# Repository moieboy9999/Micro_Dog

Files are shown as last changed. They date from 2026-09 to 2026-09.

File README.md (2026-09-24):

# Micro Dog

-Since the creator is Korean, the filename contains Korean.-

A 0.96 kg, 12-DOF quadruped driven by 12 × Dynamixel XL330-M288-T servos. It is built around a
Raspberry Pi Zero 2 W and uses a parallelogram four-bar knee.

This repository contains the complete mechanical design and the simulation description:
- the Autodesk Inventor source;
- a neutral STEP export;
- per-link visual meshes;
- a URDF with measured masses and joint limits;
- a flattened USD for Isaac Sim / Isaac Lab;
- the scripts that regenerate the URDF from the CAD data;
- the trained walking policy that runs on the robot (`policy/`).

[한국어 요약](README.ko.md) · [Notes from the creator](A%20small%20note%20from%20the%20creator.md)

> **Bill of materials: coming soon.** A full BOM (electronics, bearings, fasteners, printed parts
> with quantities and filament estimate) will be added in a later update.

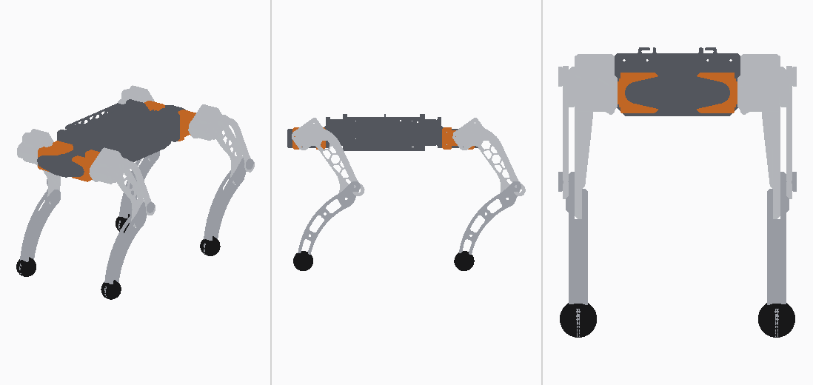
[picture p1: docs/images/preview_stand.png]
Micro Dog in its standing pose


| | |
|---|---|
| Mass | **0.960 kg** (weighed) |
| Size | 334.5 × 165.5 × 145.2 mm (assembly pose) |
| Degrees of freedom | 12: hip roll, thigh pitch, knee pitch per leg |
| Actuators | 12 × Dynamixel XL330-M288-T (Protocol 2.0) |
| Legs | thigh 95.0 mm, shank 97.0 mm, foot radius 13.0 mm |
| Hip spacing | 206.0 mm fore-aft, 58.0 mm across |
| Standing height | 0.170 m nominal |
| Compute | Raspberry Pi Zero 2 W with a Pollen Robotics RPI Robot HAT |
| Power | 2-cell lithium pack, BMS and charging module |
| Material | PLA (3D printed) for all printed parts: frame, legs, body cover; TPU-95A feet; knee pushrod links machined from 6061 aluminium in the author's build (PLA links are strong enough) |

---

## Contents

```
urdf/micro_dog.urdf        the model: 17 links, 16 joints (12 revolute + 4 fixed feet)
meshes/visual/*.stl        9 binary STLs (~19 MB), visual only; paths are relative to the URDF
step/micro_dog.step        full assembly, neutral CAD exchange (Inventor export)
usd/micro_dog.usda         pre-converted and flattened asset for Isaac Sim / Isaac Lab
params/robot_params.yaml   masses, inertias, joint origins, measured limits, actuator constants
params/*.json              raw Inventor dumps (assembly tree, mass properties) the params derive from
cad/inventor/              Autodesk Inventor 2027 source (assembly + parts)
tools/                     generate_urdf.py, derive_params.py, bake_meshes.py, stl_io.py
docs/specs.md              coordinate frames, dimensions, mass budget, knee linkage, servo zero/sign
docs/body_cover.md         the body cover, which is in the Inventor source but not in the URDF
policy/                    trained walking policy (RSL-RL checkpoint) and its deployment contract
```

**Which version is which.**
- `urdf/`, `meshes/`, `step/`, `usd/` and `params/` are the **2026-08-23 CAD export**. That is the
  version used for all simulation and training.
- `cad/inventor/` is the **current design (2026-09-21)**. It adds the body cover and small revisions
  to the foot and the Pi mount.
- The body cover is not in the simulation model. It is printed in PLA: about 50.8 g if
  solid, less with infill (see `docs/body_cover.md`).

---

## Loading the model

**Isaac Sim / Isaac Lab.** Start with `usd/micro_dog.usda`. It is already converted and flattened,
with no external references and no absolute paths.

If you convert the URDF yourself, **flatten the result**. The Isaac Sim URDF importer nests links
as a kinematic tree (`base/FL_hip/FL_thigh/...`). Isaac Lab's contact sensing assumes the flat
layout of its stock assets. In the nested layout only `base` gets `PhysxContactReportAPI`, and the
feet silently report no contacts.

**Other simulators (ROS, PyBullet, MuJoCo import, …).** Load `urdf/micro_dog.urdf`. Keep `urdf/` and
`meshes/` side by side, because meshes are referenced as `../meshes/visual/*.stl`.

Link and joint names follow the Unitree Go2 convention, so Go2 configurations need few edits:

```
base
 └ {FL,FR,RL,RR}_hip    ← *_hip_joint    revolute, axis (1,0,0)  roll
    └ *_thigh           ← *_thigh_joint  revolute, axis (0,1,0)  pitch
       └ *_calf         ← *_calf_joint   revolute, axis (0,1,0)  knee
          └ *_foot      ← *_foot_joint   fixed
```

Frame: ROS convention (+X forward, +Y left, +Z up); SI units.

## Joints

**Zero pose** is the CAD assembly pose, with every servo centred at 2048 ticks. At zero the thighs
point straight back and the shanks straight down.

| Joint | Axis | Lower (rad) | Upper (rad) |
|---|---|---:|---:|
| `*_hip_joint`, left (FL, RL) | `1 0 0` | −1.5555 | +0.8606 |
| `*_hip_joint`, right (FR, RR) | `1 0 0` | −0.8606 | +1.5555 |
| `*_thigh_joint` | `0 1 0` | −1.5278 | +0.8590 |
| `*_calf_joint` | `0 1 0` | −1.1014 | +1.2072 |

- **Limits** were measured on the assembled robot. The hip limits are mirrored between left and
  right.
- **Every revolute joint** has effort 0.6405 N·m and velocity 20.22 rad/s. These are the XL330
  values at this robot's supply voltage.
- **Joint dynamics** are damping 0.00536 and friction 0.00477.

**The knee is exact, not approximated.** The knee servo sits in the thigh and drives the shank
through a parallelogram four-bar (crank 19 mm, pushrod 95 mm). The shank angle relative to the
thigh therefore equals the servo angle 1:1. See `docs/specs.md` §3.

## Masses

| Link | Mass (kg) | ×4 |
|---|---:|---:|
| `base` | 0.45564 | — |
| `*_hip` | 0.03357 | 0.13428 |
| `*_thigh` | 0.06676 | 0.26704 |
| `*_calf` | 0.02376 | 0.09504 |
| `*_foot` | 0.00200 | 0.00800 |
| **Total** | | **0.96000** |

- The CAD sums to 912.6 g and the weighed robot is 960 g.
- The 47.4 g difference (wiring, screws, glue) is spread evenly over the four thighs and four
  calves.
- Their inertia tensors are scaled by the same ratio.

## Collision model: read this before you trust contacts

Collision uses **primitives only**: 13 boxes and 4 foot spheres of radius 0.013 m. There are no
collision meshes.

The foot sphere's lowest point matches the real foot tip (within 0.1 mm), so contact **height** is
right. The real foot is a thin blade, though, so contact **width** is about 2× too generous
laterally. For slip or contact-patch studies, model the real geometry. For gait and balance work
the sphere is fine.

## Regenerating the URDF

```
python tools/derive_params.py     # params/*.json (Inventor dumps) -> params/robot_params.yaml
python tools/generate_urdf.py     # params/robot_params.yaml       -> urdf/micro_dog.urdf
python tools/bake_meshes.py --raw <dir with raw Inventor STL exports>   # -> meshes/visual/
```

- `generate_urdf.py` reproduces `urdf/micro_dog.urdf` exactly from the shipped params (line endings follow your OS).
- The raw per-document STL exports (~240 MB) are not shipped. Export them from `cad/inventor/`.
- Requires Python 3 with `numpy` and `pyyaml`.

## Inventor source

- Open `cad/inventor/micro_dog.ipj` as the Inventor project, then `cad/inventor/전체.iam`
  ("full assembly"). The project workspace is the folder itself, so the set works from any
  location.
- The files were made with **Autodesk Inventor 2027 Education**. Inventor marks them as
  educational, and that mark stays with them if they are opened in a commercial seat.
- File names are Korean. Key terms: 다리 = leg, 몸 = body, 부품 = purchased parts, 허벅지 = thigh,
  종아리 = shank, 발 = foot, 프레임 = frame, 커버 = cover.
- **One model is not included:** `몸/시스템/Raspberry Pi Zero 2 W.ipt`. It is a third-party model.
  Download a Raspberry Pi Zero 2 W STEP model (for example from the official Raspberry Pi
  product page), import it into Inventor and save it under that name and path to restore the
  assembly. Everything else resolves inside this folder.

## Not included

- The actuator model: friction, torque–speed curve, transport delay.
- The training environment code. The walking policy and its observation/action contract are in
  `policy/`.
- IMU placement and calibration. Servo signs and IDs are in `docs/specs.md` §4. The homing offsets
  in `params/robot_params.yaml → hardware` belong to the author's unit; yours will differ.
- Bill of materials (coming soon), printing and assembly instructions.

## License

- **Hardware, documentation and the policy weights** (CAD, STEP, STL, URDF, USD, params, docs,
  policy) are licensed under
  **CC BY-NC-SA 4.0** — see [LICENSE](LICENSE).
- **Scripts in `tools/`** are licensed under **GPL-3.0-or-later** — see
  [LICENSE-SOFTWARE](LICENSE-SOFTWARE).
- Third-party components and credits: [ATTRIBUTION.md](ATTRIBUTION.md).

© 2026 moieboy9999

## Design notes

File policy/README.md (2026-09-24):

# Walking policy (`micro_dog_walk.pt`)

This is the velocity-tracking walking policy that runs on the author's Micro Dog, on gamepad button A
(deployed 2026-09-20). It was trained in Isaac Lab with RSL-RL (PPO) and walked on the real robot.

| File | Contents |
|---|---|
| `micro_dog_walk.pt` | RSL-RL checkpoint, update 30000: actor, critic, optimizer state, curriculum state |
| `micro_dog_walk.json` | Deployment contract: observation layout, action formula, joint order, limits, hardware settings |

## Network

- **Actor:** MLP 45 → 512 → 256 → 128 → 12, ELU activations, in `actor_state_dict` (`mlp.0/2/4/6`).
  It has no observation normalisation and no history.
- **Output:** the deterministic action is the MLP output. `distribution.log_std_param` is the training
  exploration noise; ignore it at deployment.
- **Timing:** it runs at 50 Hz (`step_dt` 0.02 s).

## Observation (45 values, raw SI units, no scaling)

| Index | Term | Meaning |
|---|---|---|
| 0–2 | `base_ang_vel` | IMU gyro, body frame, rad/s |
| 3–5 | `projected_gravity` | gravity unit vector in the body frame (complementary filter, α = 0.01) |
| 6–8 | `velocity_commands` | [vx m/s, vy m/s, yaw rate rad/s] |
| 9–20 | `joint_pos` | joint angle **minus** `default_joint_pos`, rad |
| 21–32 | `joint_vel` | joint velocity, rad/s |
| 33–44 | `actions` | previous raw policy output |

**Joint order is grouped by joint type, not by leg.** It is the `joint_names` list in the JSON:

```
FL_hip  FR_hip  RL_hip  RR_hip  FL_thigh  FR_thigh  RL_thigh  RR_thigh  FL_calf  FR_calf  RL_calf  RR_calf
```

This differs from the per-leg order of the URDF, so map by name.

## Action

```
target = clip(raw_action * 0.25 + default_joint_pos, clip_low, clip_high)     # rad, joint_names order
```

`default_joint_pos`, `clip_low` and `clip_high` are in the JSON. Send `target` to the servos as
position setpoints.

## Hardware assumptions

- **Servos:** XL330-M288-T in position mode, firmware P gain 200. Profile velocity is 843 and
  profile acceleration 0, so the servo's own velocity profile shapes the step. The host sends raw
  targets.
- **Angle mapping:** servo tick ↔ joint angle uses `docs/specs.md` §4.
- **Training commands:** the curriculum's final stage covered |vx| ≤ 0.70 m/s, |vy| ≤ 0.50 m/s and
  |yaw rate| ≤ 1.8 rad/s. Speeds validated on hardware are lower. Start slow.
- **Physics:** the simulated actuator, IMU and friction models it was trained against are described in
  the JSON (`physics_contract`, `imu_contract`). The training environment code is not included.
- **Torque limit:** training used a PWM/voltage torque model with an effort limit of 0.549 N·m
  (`physics_contract.effort_limit_nm`). That is stricter than the 0.6405 N·m on the URDF joints, which
  is the plain rigid-body description.

## Safety

- This is a learned controller for a small robot.
- Test with the robot lifted, then at low commanded speed.
- Keep a torque-off button within reach.
- The servos' current-limit register is not enforced in position mode (see `physics_contract`).

License: CC BY-NC-SA 4.0, like the rest of the design files.

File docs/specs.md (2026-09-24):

# Micro Dog — design specifications

This document derives the URDF from the Inventor CAD. All dimensions come from the assembly. Total
mass, servo gain and supply voltage were measured on the robot.

## 1. Frames

The CAD assembly frame is +X forward, +Y up, +Z right. The URDF uses the ROS convention: +X
forward, +Y left, +Z up. One fixed rotation maps between them:

```
p_urdf = M · p_cad        M = [[1, 0, 0],
                               [0, 0,-1],
                               [0, 1, 0]]
```

The `base` origin is the centre of the four hip-roll axes, the same convention as Go2.

## 2. Dimensions (from CAD)

| Item | Value |
|---|---|
| Hip-roll axis spacing, fore-aft | 206.0 mm |
| Hip-roll axis spacing, across | 58.0 mm |
| Roll axis → leg plane (lateral offset) | 39.8 mm |
| Thigh (pitch axis → knee axis) | 95.0 mm |
| Shank (knee axis → foot pad centre) | 97.0 mm |
| Foot radius (TPU-95A foot) | 13.0 mm |
| Knee axis → ground contact | 110.0 mm |
| Track width (left–right foot spacing) | 137.6 mm |
| Maximum leg extension | 205.0 mm |

The roll, pitch and knee axes all lie in one horizontal plane, and the roll and pitch axes
intersect. The only `hip_joint → thigh_joint` offset is therefore the 39.8 mm lateral one.

### Mass budget

| Link | Mass | Contents |
|---|---|---|
| `base` | 455.6 g | frame 220.6 g; system 235.0 g (2 batteries, Pi + HAT, BMS, charger, fan, switch); 4 roll servos |
| `*_hip` ×4 | 33.6 g | roll horn frame, pitch servo, bearing |
| `*_thigh` ×4 | 66.8 g | thigh shell 22.0, XL330 22.0, large bearing 2.0, crank 2.6, pushrod 12.2 (6061 aluminium; the CAD models it at about 3.0 g/cm³, i.e. metal), **measured makeup 5.9** |
| `*_calf` ×4 | 23.8 g | shank + foot assembly minus the foot tip, **measured makeup 5.9** |
| `*_foot` ×4 | 2.0 g | TPU-95A foot tip |
| **Total** | **960.0 g** | CAD 912.6 g + makeup 47.4 g |

**Measured makeup.** The assembled robot weighs 960 g against a CAD total of 912.6 g.
- The 47.4 g the CAD does not carry is wiring, screws and glue.
- The servo cables run down the legs, so it is split evenly over the four thighs and four calves:
  +5.925 g per link.
- Each link's inertia tensor is scaled by the same ratio.
- A point mass at the COM would leave the inertia unchanged and under-state leg swing inertia.

**Material density.** CAD part masses use Inventor's ABS density (1.06 g/cm³), except where a
mass is overridden (the thigh shell is fixed at 22.0 g). All printed parts are PLA
(about 1.24 g/cm³). The weighed total of 960 g is exact. The split between links still assumes ABS
density for the printed parts.

Inertia tensors come from Inventor `MassProperties`: about the COM, in assembly axes, converted
from kg·cm² to kg·m². The sign and order convention was checked against the principal moments.

## 3. Knee: four-bar → one revolute joint

The knee servo sits in the thigh. It drives crank → pushrod → shank crank arm → shank.

| Link | Length |
|---|---|
| Thigh (ground link) | 95.0 mm |
| Crank | 19.0 mm |
| Pushrod | 95.0 mm |
| Shank crank arm | 19.0 mm |

This is an exact parallelogram, so the crank and the shank arm stay parallel. The shank angle
relative to the thigh equals the knee servo angle 1:1, with no coupling term. A single revolute
knee is therefore an exact equivalent model, not an approximation.

The pushrod (12.2 g) and crank (2.6 g) are merged into the thigh link. In a parallelogram the
pushrod always moves parallel to the thigh, so this is physically sound.

## 4. Joint zero and servo mapping

`q = 0` is the CAD assembly pose. All 12 servos are at 2048 ticks (180°). The thigh points
straight back and the shank straight down.

```
tick = 2048 + sign · q · 4096/(2π) + offset_tick
q    = sign · (tick − 2048 − offset_tick) · 2π/4096
```

| Joint | FL | FR | RL | RR |
|---|---|---|---|---|
| hip | +1 | +1 | −1 | −1 |
| thigh | +1 | −1 | +1 | −1 |
| calf | +1 | −1 | +1 | −1 |

Servo IDs are leg-major:

| | FL | FR | RL | RR |
|---|---|---|---|---|
| hip roll | 11 | 21 | 31 | 41 |
| thigh pitch | 12 | 22 | 32 | 42 |
| knee pitch | 13 | 23 | 33 | 43 |

### Poses

| Pose | hip | thigh | calf | base height |
|---|---|---|---|---|
| `zero` (assembly) | 0 | 0 | 0 | 0.110 m |
| `stand` (kinematic target) | 0 | −0.9500 | +0.3440 | 0.170 m |
| `stand_balanced` (COM over support centre) | 0 | −0.8380 | +0.3658 | 0.170 m |
| `stand_compensated` (commanded, under gravity) | +0.0084 | −0.8149 | +0.5002 | 0.168 m (target 0.170) |

`stand_compensated` is the command whose steady state under gravity approximates `stand_balanced`.
The XL330 position loop has finite stiffness, so the commanded angles have to lead the target. All
poses, including 0.155 m variants, are in `params/robot_params.yaml → poses`, which is the source
of truth for these values.

## 5. Actuator constants

`params/robot_params.yaml → actuator` holds these constants for the XL330-M288-T:
- effort limit and velocity limit;
- torque constant, winding resistance and armature;
- friction.

The friction and motor constants come from Rhoban BAM (`xl330/m6.json`; see ATTRIBUTION.md). The
effort and velocity limits are evaluated at this robot's supply voltage.

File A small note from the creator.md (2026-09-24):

1. I made the leg links using machined aluminum, but they also achieve sufficient strength when 3D printed. (무릎 링크는 3D 프린터로 뽑아도 충분할 겁니다.)
2. Honestly, the cooling fan seems pointless. (냉각팬이 제 역할을 하는지 모르겠습니다.)
3. The XL330-M288T is affordable and suitable for walking and light jogging, but anything beyond that is too much, so I recommend purchasing extra gear. A better option is to buy the XC330-M288T. (걷기, 경보정도는 XL로도 가능하지만 그 이상은 기어파손이 발생하니 여분 기어 구매를 권장합니다. 아니면 XC로 가도 좋아요 :>)
4. The feet are made of TPU-95A. Please make the internal filling and walls as smooth as possible. (발은 TPU-95A로 만들었습니다. 내부 채움과 벽은 최대한 부드럽게 만드시기 바랍니다.)
5. AI will explain it better than I can. (AI가 저보다 잘 설명할겁니다.)
6. If you have any further questions, please contact me via Instagram DM. My ID is: davidchois1234 (궁금한 점은 인스타 DM으로 문의주세요 ID: davidchois1234)
7.

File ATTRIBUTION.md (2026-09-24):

# Attribution and third-party components

The Micro Dog mechanical design was modelled by the author and is released under CC BY-NC-SA 4.0
(see `LICENSE`). That covers:
- every part in `cad/inventor/` except the ROBOTIS XL330 models (`부품/XL,XC-330*.ipt`). That
  includes all printed frames, brackets, links, legs, feet and the body cover, and the envelope
  models of the purchased electronics and bearings, `BMS.ipt` among them;
- the STEP, meshes, URDF and USD derived from it.

The servo horns are the stock horns supplied with the XL330 (ROBOTIS). They are part of the
ROBOTIS servo model, not a separate design.

## Inspiration

**Rhoban Microban** — <https://github.com/Rhoban/microban>
- Micro Dog took its system layout and bill-of-materials idea from Microban: Pi Zero 2 W,
  XL330 servos, a HAT, 2-cell lithium power with BMS and charger.
- No Microban CAD, STL, STEP or source files are included or derived here.
- Microban is licensed CC BY-NC-SA 4.0 (hardware/docs) and GPL-3.0 (software).

## Components used by the robot (not redistributed here)

| Component | Source | License | In this repository |
|---|---|---|---|
| Pollen Robotics RPI Robot HAT | <https://github.com/pollen-robotics/elec_RPI_Robot_HAT> | Apache-2.0 | Not included. `cad/inventor/부품/라파+hat.ipt` is a self-made envelope model of the board, not the PCB design. |
| Raspberry Pi Zero 2 W | Raspberry Pi Ltd. | — | 3D model **not included** (third-party model); see README → Inventor source. |

## Third-party data and models included

| Item | Source | Notes |
|---|---|---|
| Dynamixel XL330-M288-T CAD model (`cad/inventor/부품/XL,XC-330.ipt`, `XL,XC-330_MIR.ipt`); XL330 geometry fused into the STEP and visual meshes | ROBOTIS, public CAD download (<https://emanual.robotis.com/docs/en/dxl/x/xl330-m288/>) | © ROBOTIS. Included for assembly completeness. |
| XL330 actuator friction / motor constants in `params/robot_params.yaml` (`actuator` block) | Rhoban BAM, `bam/params/xl330/m6.json` — <https://github.com/Rhoban/bam> | Apache-2.0 |

Link and joint names follow the Unitree Go2 naming convention. No Unitree assets are included.

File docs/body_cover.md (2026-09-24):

# Body cover

The body cover is `cad/inventor/몸/커버/몸커버.ipt` ("body cover"). It was added to the design on
2026-09-13, after the 2026-08-23 export that the URDF, STEP, meshes and USD come from. **It is not
part of the simulation model.**

| Property | Value |
|---|---|
| Material in CAD | ABS (1.06 g/cm³) |
| Volume | 40.9 cm³ |
| CAD mass (solid ABS density) | 43.4 g |
| Solid mass in PLA (1.24 g/cm³), the material actually used | ~50.8 g |

- **How much it weighs is not settled.** The cover is printed in PLA. A fully solid PLA cover
  would weigh about 50.8 g; with infill it weighs less, so weigh your own print.
- **The URDF total of 0.960 kg was weighed before the cover was fitted.** A robot with the cover
  is heavier by the cover's printed mass.
- **To include the cover in simulation,** add its measured mass to the `base` link. It mounts on
  the body, so treat it as part of `base`. Then scale the `base` inertia or recompute it from CAD.
- For gait work at the current fidelity, the model has been used without the cover.

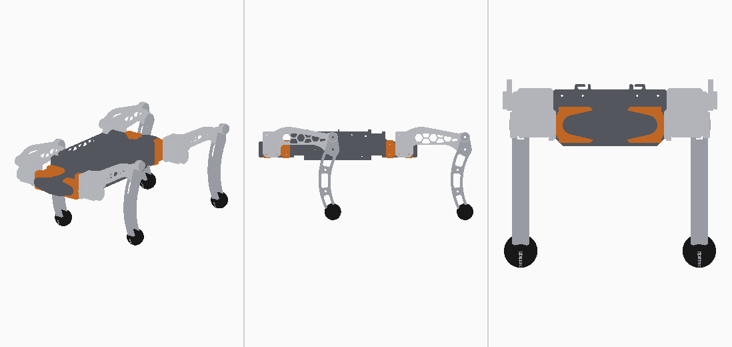
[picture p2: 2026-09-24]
docs/images/preview_zero.png

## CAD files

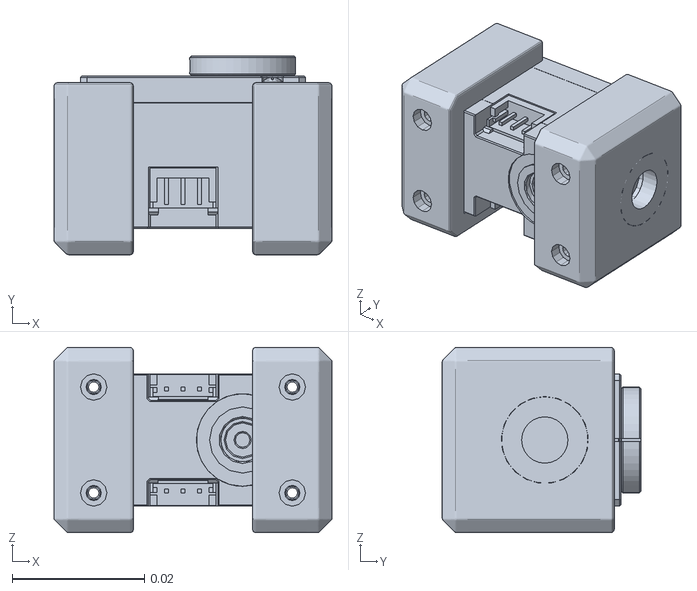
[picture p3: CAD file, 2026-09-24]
meshes/visual/hip_fl.stl
0.042 x 0.03 x 0.028

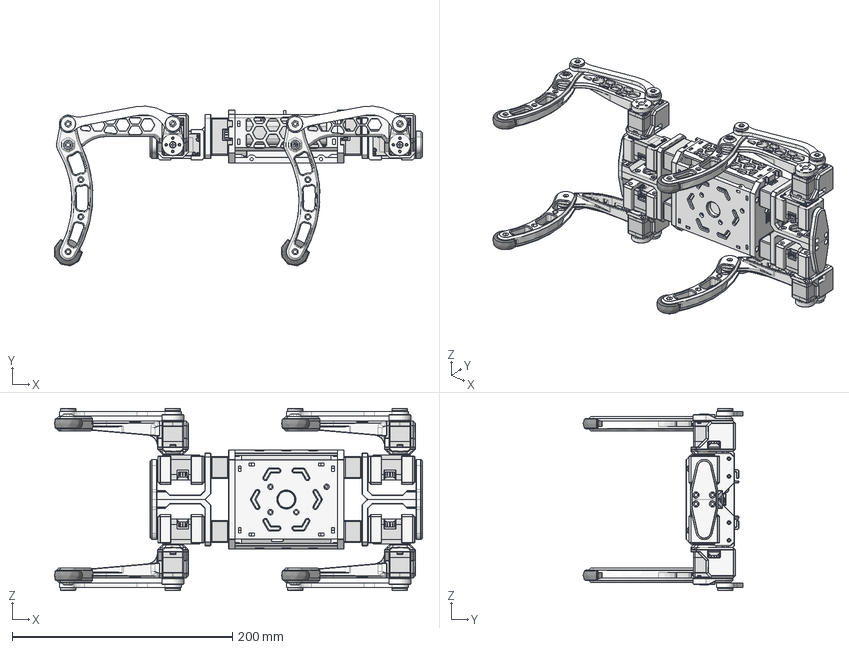
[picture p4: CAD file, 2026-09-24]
step/micro_dog.step
333.8 x 145.0 x 165.5 mm
라파+hat
tmdnlcl
몸프레임
배터리+홀더 x 2
BMS
충전모듈
팬
다리 프레임
다리 프레임_1
아래프레임
XL,XC-330 x 12
롤축지지대 x 2
롤축지지대_MIR x 2
롤축지지대베어링 x 4
사이드프레임 x 2
롤프레임혼1 x 4
롤프레임혼1_1 x 4
큰베어링4 x 8
허벅지 x 2
종아리_2 x 4
종아리 x 2
종아리_1 x 2
축종아리베어링고정 x 4
링크 고정 x 8
링크축 x 4
링크_1 x 4
작은베어링 x 8
종아리_MIR x 2
링크축종아리_MIR x 2
허벅지_MIR x 2

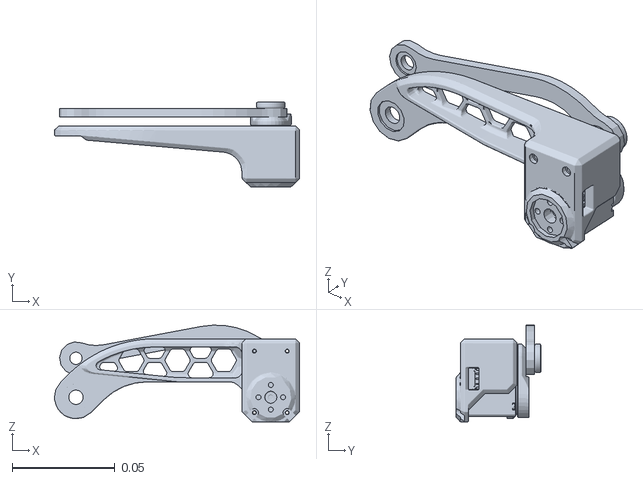
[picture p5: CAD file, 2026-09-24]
meshes/visual/thigh_left.stl
0.119 x 0.0412 x 0.0472

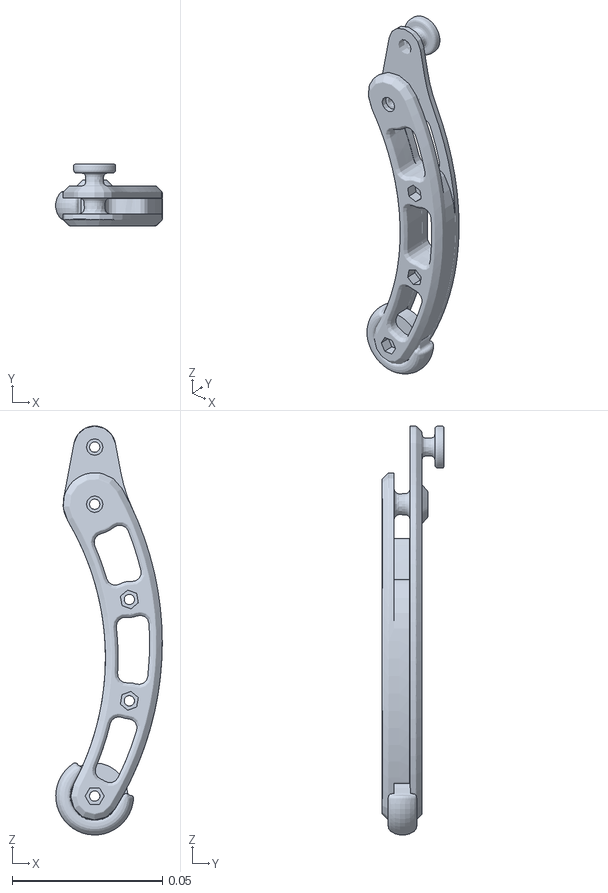
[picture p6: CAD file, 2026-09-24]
meshes/visual/calf_left.stl
0.0354 x 0.0205 x 0.136

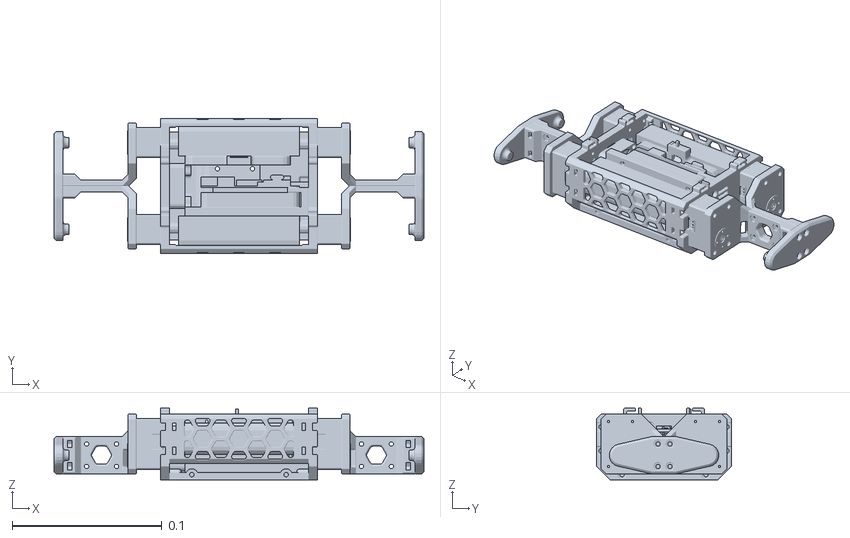
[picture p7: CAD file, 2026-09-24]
meshes/visual/base.stl
0.247 x 0.09 x 0.048

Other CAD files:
meshes/visual/hip_rl.stl
meshes/visual/thigh_right.stl
meshes/visual/hip_fr.stl
meshes/visual/calf_right.stl
meshes/visual/hip_rr.stl
cad/inventor/다리/프레임/roll축뒷다리.iam
cad/inventor/다리/프레임/roll축앞다리.iam
cad/inventor/다리/프레임/롤프레임베어링.ipt
cad/inventor/다리/프레임/롤프레임혼.ipt
cad/inventor/다리/프레임/링크 고정.ipt
cad/inventor/다리/프레임/링크.iam
cad/inventor/다리/프레임/링크.ipt
cad/inventor/다리/프레임/링크축.ipt
cad/inventor/다리/프레임/링크축종아리.ipt
cad/inventor/다리/프레임/링크축종아리_MIR.ipt
cad/inventor/다리/프레임/발.ipt
cad/inventor/다리/프레임/오른종아리발.iam
cad/inventor/다리/프레임/오른허벅지.iam
cad/inventor/다리/프레임/왼종아리발.iam
cad/inventor/다리/프레임/왼허벅지.iam
cad/inventor/다리/프레임/종아리.ipt
cad/inventor/다리/프레임/종아리_MIR.ipt
cad/inventor/다리/프레임/축종아리베어링고정.ipt
cad/inventor/다리/프레임/허벅지.ipt
cad/inventor/다리/프레임/허벅지_MIR.ipt
cad/inventor/다리/프레임/혼축링크.iam
cad/inventor/라파hat간띄.ipt
cad/inventor/몸/몸.iam
cad/inventor/몸/시스템/마운트.ipt
cad/inventor/몸/시스템/시스템조립.iam
cad/inventor/몸/커버/몸커버.ipt
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

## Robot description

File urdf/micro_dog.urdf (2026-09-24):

<?xml version="1.0"?>
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
<robot name="micro_dog">

  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

  <link name="base">
    <inertial>
      <origin xyz="-0.01785849 -0.00060131919 0.0060383162" rpy="0 0 0"/>
      <mass value="0.45564345"/>
      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
    </inertial>
    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
  </link>

  <link name="FL_hip">
    <inertial>
      <origin xyz="-0.0060982512 -0.00094346636 2.9601791e-06" rpy="0 0 0"/>
      <mass value="0.033571869"/>
      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
    </inertial>
    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
  </link>

  <link name="FL_thigh">
    <inertial>
      <origin xyz="-0.022583808 -0.0043976799 0.012714785" rpy="0 0 0"/>
      <mass value="0.066755916"/>
      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
    </inertial>
    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
  </link>

  <link name="FL_calf">
    <inertial>
      <origin xyz="0.0075692784 0.00036662655 -0.036778283" rpy="0 0 0"/>
      <mass value="0.023761353"/>
      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
    </inertial>
    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
  </link>

  <link name="FL_foot">
    <inertial>
      <origin xyz="0 0 0" rpy="0 0 0"/>
      <mass value="0.002"/>
      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
    </inertial>
    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
  </link>

  <link name="FR_hip">
    <inertial>
      <origin xyz="-0.0060982512 0.00094346636 -2.9601791e-06" rpy="0 0 0"/>
      <mass value="0.033571869"/>
      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
    </inertial>
    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
  </link>

  <link name="FR_thigh">
    <inertial>
      <origin xyz="-0.022587077 0.0043976796 0.012714785" rpy="0 0 0"/>
      <mass value="0.066755916"/>
      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
    </inertial>
    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
  </link>

  <link name="FR_calf">
    <inertial>
      <origin xyz="0.0075692784 -0.00079929557 -0.036778283" rpy="0 0 0"/>
      <mass value="0.023761353"/>
      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
    </inertial>
    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
  </link>

  <link name="FR_foot">
    <inertial>
      <origin xyz="0 0 0" rpy="0 0 0"/>
      <mass value="0.002"/>
      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
    </inertial>
    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
  </link>

  <link name="RL_hip">
    <inertial>
      <origin xyz="0.0060982512 -0.00094346636 -2.9601791e-06" rpy="0 0 0"/>
      <mass value="0.033571869"/>
      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
    </inertial>
    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
  </link>

  <link name="RL_thigh">
    <inertial>
      <origin xyz="-0.022583808 -0.0043976799 0.012714785" rpy="0 0 0"/>
      <mass value="0.066755916"/>
      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
    </inertial>
    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
  </link>

  <link name="RL_calf">
    <inertial>
      <origin xyz="0.0075692784 0.00036662655 -0.036778283" rpy="0 0 0"/>
      <mass value="0.023761353"/>
      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
    </inertial>
    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
  </link>

  <link name="RL_foot">
    <inertial>
      <origin xyz="0 0 0" rpy="0 0 0"/>
      <mass value="0.002"/>
      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
    </inertial>
    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
  </link>

  <link name="RR_hip">
    <inertial>
      <origin xyz="0.0060982512 0.00094346636 2.9601791e-06" rpy="0 0 0"/>
      <mass value="0.033571869"/>
      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
    </inertial>
    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
  </link>

  <link name="RR_thigh">
    <inertial>
      <origin xyz="-0.022587077 0.0043976796 0.012714785" rpy="0 0 0"/>
      <mass value="0.066755916"/>
      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
    </inertial>
    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
  </link>

  <link name="RR_calf">
    <inertial>
      <origin xyz="0.0075692784 -0.00079929557 -0.036778283" rpy="0 0 0"/>
      <mass value="0.023761353"/>
      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
    </inertial>
    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
  </link>

  <link name="RR_foot">
    <inertial>
      <origin xyz="0 0 0" rpy="0 0 0"/>
      <mass value="0.002"/>
      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
    </inertial>
    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
  </link>

  <joint name="FL_hip_joint" type="revolute">
    <parent link="base"/>
    <child link="FL_hip"/>
    <origin xyz="0.103 0.029 0" rpy="0 0 0"/>
    <axis xyz="1 0 0"/>
    <limit lower="-1.5554565" upper="0.86056322" effort="0.64052362" velocity="20.217834"/>
    <dynamics damping="0.0053596683" friction="0.0047711832"/>
  </joint>

  <joint name="FL_thigh_joint" type="revolute">
    <parent link="FL_hip"/>
    <child link="FL_thigh"/>
    <origin xyz="0 0.0398 0" rpy="0 0 0"/>
    <axis xyz="0 1 0"/>
    <limit lower="-1.5278449" upper="0.85902924" effort="0.64052362" velocity="20.217834"/>
    <dynamics damping="0.0053596683" friction="0.0047711832"/>
  </joint>

  <joint name="FL_calf_joint" type="revolute">
    <parent link="FL_thigh"/>
    <child link="FL_calf"/>
    <origin xyz="-0.095 0 0" rpy="0 0 0"/>
    <axis xyz="0 1 0"/>
    <limit lower="-1.1013982" upper="1.2072429" effort="0.64052362" velocity="20.217834"/>
    <dynamics damping="0.0053596683" friction="0.0047711832"/>
  </joint>

  <joint name="FL_foot_joint" type="fixed">
    <parent link="FL_calf"/>
    <child link="FL_foot"/>
    <origin xyz="0 0 -0.097" rpy="0 0 0"/>
  </joint>

  <joint name="FR_hip_joint" type="revolute">
    <parent link="base"/>
    <child link="FR_hip"/>
    <origin xyz="0.103 -0.029 0" rpy="0 0 0"/>
    <axis xyz="1 0 0"/>
    <limit lower="-0.86056322" upper="1.5554565" effort="0.64052362" velocity="20.217834"/>
    <dynamics damping="0.0053596683" friction="0.0047711832"/>
  </joint>

  <joint name="FR_thigh_joint" type="revolute">
    <parent link="FR_hip"/>
    <child link="FR_thigh"/>
    <origin xyz="0 -0.0398 0" rpy="0 0 0"/>
    <axis xyz="0 1 0"/>
    <limit lower="-1.5278449" upper="0.85902924" effort="0.64052362" velocity="20.217834"/>
    <dynamics damping="0.0053596683" friction="0.0047711832"/>
  </joint>

  <joint name="FR_calf_joint" type="revolute">
    <parent link="FR_thigh"/>
    <child link="FR_calf"/>
    <origin xyz="-0.095 0 0" rpy="0 0 0"/>
    <axis xyz="0 1 0"/>
    <limit lower="-1.1013982" upper="1.2072429" effort="0.64052362" velocity="20.217834"/>
    <dynamics damping="0.0053596683" friction="0.0047711832"/>
  </joint>

  <joint name="FR_foot_joint" type="fixed">
    <parent link="FR_calf"/>
    <child link="FR_foot"/>
    <origin xyz="0 0 -0.097" rpy="0 0 0"/>
  </joint>

  <joint name="RL_hip_joint" type="revolute">
    <parent link="base"/>
    <child link="RL_hip"/>
    <origin xyz="-0.103 0.029 0" rpy="0 0 0"/>
    <axis xyz="1 0 0"/>
    <limit lower="-1.5554565" upper="0.86056322" effort="0.64052362" velocity="20.217834"/>
    <dynamics damping="0.0053596683" friction="0.0047711832"/>
  </joint>

  <joint name="RL_thigh_joint" type="revolute">
    <parent link="RL_hip"/>
    <child link="RL_thigh"/>
    <origin xyz="0 0.0398 0" rpy="0 0 0"/>
    <axis xyz="0 1 0"/>
    <limit lower="-1.5278449" upper="0.85902924" effort="0.64052362" velocity="20.217834"/>
    <dynamics damping="0.0053596683" friction="0.0047711832"/>
  </joint>

  <joint name="RL_calf_joint" type="revolute">
    <parent link="RL_thigh"/>
    <child link="RL_calf"/>
    <origin xyz="-0.095 0 0" rpy="0 0 0"/>
    <axis xyz="0 1 0"/>
    <limit lower="-1.1013982" upper="1.2072429" effort="0.64052362" velocity="20.217834"/>
    <dynamics damping="0.0053596683" friction="0.0047711832"/>
  </joint>

  <joint name="RL_foot_joint" type="fixed">
    <parent link="RL_calf"/>
    <child link="RL_foot"/>
    <origin xyz="0 0 -0.097" rpy="0 0 0"/>
  </joint>

  <joint name="RR_hip_joint" type="revolute">
    <parent link="base"/>
    <child link="RR_hip"/>
    <origin xyz="-0.103 -0.029 0" rpy="0 0 0"/>
    <axis xyz="1 0 0"/>
    <limit lower="-0.86056322" upper="1.5554565" effort="0.64052362" velocity="20.217834"/>
    <dynamics damping="0.0053596683" friction="0.0047711832"/>
  </joint>

  <joint name="RR_thigh_joint" type="revolute">
    <parent link="RR_hip"/>
    <child link="RR_thigh"/>
    <origin xyz="0 -0.0398 0" rpy="0 0 0"/>
    <axis xyz="0 1 0"/>
    <limit lower="-1.5278449" upper="0.85902924" effort="0.64052362" velocity="20.217834"/>
    <dynamics damping="0.0053596683" friction="0.0047711832"/>
  </joint>

  <joint name="RR_calf_joint" type="revolute">
    <parent link="RR_thigh"/>
    <child link="RR_calf"/>
    <origin xyz="-0.095 0 0" rpy="0 0 0"/>
    <axis xyz="0 1 0"/>
    <limit lower="-1.1013982" upper="1.2072429" effort="0.64052362" velocity="20.217834"/>
    <dynamics damping="0.0053596683" friction="0.0047711832"/>
  </joint>

  <joint name="RR_foot_joint" type="fixed">
    <parent link="RR_calf"/>
    <child link="RR_foot"/>
    <origin xyz="0 0 -0.097" rpy="0 0 0"/>
  </joint>

</robot>

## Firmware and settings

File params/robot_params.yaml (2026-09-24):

meta:
  name: micro_dog
  description: Micro Dog quadruped, self-modelled parts inspired by Rhoban Microban (Dynamixel XL330-M288-T x12)
  source_cad: 전체.iam (Autodesk Inventor 2027)
  units: SI (m, kg, rad)
  frame: 'ROS/URDF convention: +X forward, +Y left, +Z up'
  zero_pose: CAD assembly pose = every servo at its centre (2048 ticks / 180 deg);
    thigh points straight back, shank points straight down
  knee_linkage: parallelogram four-bar (crank 19.0 mm, pushrod 95.0 mm) -> exact 1:1
    coupling, modelled as a single revolute joint like Go2
links:
  base:
    mass: 0.45564344642235466
    com:
    - -0.017858490139421552
    - -0.0006013191939759111
    - 0.00603831619631956
    inertia:
      ixx: 0.00034771270898528294
      iyy: 0.0011755025604550924
      izz: 0.0014109362061909994
      ixy: 6.210941413952424e-06
      ixz: -2.8577857534237412e-06
      iyz: 3.133226528389969e-06
    collision:
      type: box
      size:
      - 0.2470000000000021
      - 0.09000000000000377
      - 0.048000000000005934
      origin:
      - -4.163336342344337e-17
      - -1.474514954580286e-15
      - 0.0075000000000032645
    mesh: base
  FL_hip:
    mass: 0.03357186900913004
    com:
    - -0.006098251160228187
    - -0.0009434663575089708
    - 2.960179083881798e-06
    inertia:
      ixx: 3.4319351277148142e-06
      iyy: 6.9371124064141436e-06
      izz: 7.247322879037165e-06
      ixy: -4.015909781182927e-08
      ixz: 7.263956409587991e-10
      iyz: -5.948647370132676e-10
    collision:
      type: box
      size:
      - 0.04200000000000001
      - 0.0300025912560907
      - 0.027999999999942102
      origin:
      - -0.007499999999998996
      - -0.0004987043719337511
      - 7.476658181460039e-16
    mesh: hip_fl
  FL_thigh:
    mass: 0.06675591643813134
    com:
    - -0.022583807797103877
    - -0.004397679911801689
    - 0.01271478539548385
    inertia:
      ixx: 1.560898113660963e-05
      iyy: 8.848675871202484e-05
      izz: 8.702691118874188e-05
      ixy: 1.0984716940846815e-05
      ixz: 4.3227431842676345e-06
      iyz: -2.734328974324221e-06
    collision:
      type: box
      size:
      - 0.11950741958110211
      - 0.041251781166547
      - 0.04721888371739118
      origin:
      - -0.045746290209448065
      - -0.006675890583266507
      - 0.01158786630379699
    mesh: thigh_left
  FL_foot:
    mass: 0.002
    com:
    - 0.0
    - 0.0
    - 0.0
    inertia:
      ixx: 9.954166666666666e-08
      iyy: 1.6900000000000002e-07
      izz: 9.954166666666666e-08
      ixy: 0.0
      ixz: 0.0
      iyz: 0.0
    collision:
      type: sphere
      radius: 0.013000000000000001
      origin:
      - 0.0
      - 0.0
      - 0.0
    mesh: null
  FL_calf:
    mass: 0.023761352947149948
    com:
    - 0.007569278359323253
    - 0.00036662654587951596
    - -0.03677828311605704
    inertia:
      ixx: 1.9430988156264512e-05
      iyy: 2.0373706757122745e-05
      izz: 1.8307855267633837e-06
      ixy: 1.0332010645914954e-07
      ixz: 2.448924824290345e-06
      iyz: -1.109478469239335e-06
    collision:
      type: box
      size:
      - 0.035558252616419
      - 0.020500000000001004
      - 0.1123646502064094
      origin:
      - 0.004690363911645293
      - 0.003575000000007496
      - -0.027817674896795295
    mesh: calf_left
  FR_hip:
    mass: 0.03357186900913004
    com:
    - -0.006098251160228365
    - 0.0009434663575083979
    - -2.96017908234969e-06
    inertia:
      ixx: 3.431935127715605e-06
      iyy: 6.93711240641378e-06
      izz: 7.247322879036529e-06
      ixy: 4.0159097811783794e-08
      ixz: -7.263956409587991e-10
      iyz: -5.9486473725201e-10
    collision:
      type: box
      size:
      - 0.04200000000000001
      - 0.030002591256090415
      - 0.027999999999941794
      origin:
      - -0.007499999999998996
      - 0.0004987043719328942
      - 7.016956460326185e-16
    mesh: hip_fr
  FR_thigh:
    mass: 0.06675591643813134
    com:
    - -0.022587076797228
    - 0.004397679613956977
    - 0.012714784983378635
    inertia:
      ixx: 1.5608981347769187e-05
      iyy: 8.847690769703351e-05
      izz: 8.701705925067446e-05
      ixy: -1.0984638386016745e-05
      ixz: 4.322893166046557e-06
      iyz: 2.734328900577396e-06
    collision:
      type: box
      size:
      - 0.1195074195811013
      - 0.041251781166547194
      - 0.047218883717391386
      origin:
      - -0.045746290209448655
      - 0.006675890583265992
      - 0.01158786630379629
    mesh: thigh_right
  FR_foot:
    mass: 0.002
    com:
    - 0.0
    - 0.0
    - 0.0
    inertia:
      ixx: 9.954166666666666e-08
      iyy: 1.6900000000000002e-07
      izz: 9.954166666666666e-08
      ixy: 0.0
      ixz: 0.0
      iyz: 0.0
    collision:
      type: sphere
      radius: 0.013000000000000001
      origin:
      - 0.0
      - 0.0
      - 0.0
    mesh: null
  FR_calf:
    mass: 0.023761352947149948
    com:
    - 0.007569278359317835
    - -0.0007992955680408365
    - -0.03677828311606634
    inertia:
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

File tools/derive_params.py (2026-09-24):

# -*- coding: utf-8 -*-
# SPDX-License-Identifier: GPL-3.0-or-later
# Copyright (c) 2026 moieboy9999 - Micro Dog
"""
Derive params/robot_params.yaml from the raw Autodesk Inventor dumps in ../params/*.json.

Everything in the CAD dumps is expressed in Inventor's database units
(cm, kg, kg*cm^2) in the *assembly* coordinate frame of 전체.iam:

    CAD frame :  +X = forward,  +Y = up,     +Z = robot's right
    URDF frame:  +X = forward,  +Y = left,   +Z = up      (ROS convention)

so the fixed remap between them is

    p_urdf = M @ p_cad ,   M = [[1, 0, 0],
                                [0, 0,-1],
                                [0, 1, 0]]

Joint zero (q = 0) is the CAD assembly pose, i.e. every Dynamixel sitting at
its centre position (2048 ticks / 180 deg).  In that pose the thigh points
straight backwards and the shank points straight down.

Run:  python derive_params.py
"""
import io
import json
import math
import os

import numpy as np
import yaml

HERE = os.path.dirname(os.path.abspath(__file__))
ROOT = os.path.dirname(HERE)
CAD = os.path.join(ROOT, 'params')

# CAD -> URDF axis remap
M = np.array([[1.0, 0.0, 0.0],
              [0.0, 0.0, -1.0],
              [0.0, 1.0, 0.0]])

CM = 0.01          # cm -> m
INERTIA = 1e-4     # kg*cm^2 -> kg*m^2


# --------------------------------------------------------------------------
# raw CAD data
# --------------------------------------------------------------------------
def load():
    tree = json.load(io.open(os.path.join(CAD, 'tree.json'), encoding='utf-8-sig'))
    mp = json.load(io.open(os.path.join(CAD, 'massprops.json'), encoding='utf-8-sig'))
    subs = json.load(io.open(os.path.join(CAD, 'thigh_subs.json'), encoding='utf-8-sig'))['subs']
    by_parent = {}
    for s in subs:
        by_parent.setdefault(s['parent'], []).append(s)
    return {r['path']: r for r in tree}, {r['name']: r for r in mp}, by_parent


def occ_pose(row):
    t = row['t']
    R = np.array([[t[0], t[1], t[2]],
                  [t[4], t[5], t[6]],
                  [t[8], t[9], t[10]]])
    p = np.array([t[3], t[7], t[11]])
    return R, p


def occ_bbox(row):
    lo = np.array([float(x) for x in row['rb_min'].split(',')])
    hi = np.array([float(x) for x in row['rb_max'].split(',')])
    return lo, hi


def tensor(I6):
    """Inventor XYZMomentsOfInertia -> full 3x3 tensor (verified convention:
    values are the tensor components themselves, taken about the part's own
    centre of mass, expressed in assembly axes, in kg*cm^2)."""
    ixx, iyy, izz, ixy, iyz, ixz = I6
    return np.array([[ixx, ixy, ixz],
                     [ixy, iyy, iyz],
                     [ixz, iyz, izz]])


def parallel_axis(I_com, m, d):
    """Shift an inertia tensor from the body's COM by offset d."""
    return I_com + m * (float(d @ d) * np.eye(3) - np.outer(d, d))


def combine(parts):
    """parts: list of (mass, com(3), I_about_own_com(3x3)) -> merged triple."""
    m = sum(p[0] for p in parts)
    com = sum(p[0] * p[1] for p in parts) / m
    I = np.zeros((3, 3))
    for mi, ci, Ii in parts:
        I += parallel_axis(Ii, mi, ci - com)
    return m, com, I


def subtract(whole, part):
    """Remove `part` (mass, com, I_own) from `whole` (mass, com, I_own)."""
    mw, cw, Iw = whole
    mp_, cp, Ip = part
    m = mw - mp_
    com = (mw * cw - mp_ * cp) / m
    # both expressed about `com`, then subtract
    Iw_c = parallel_axis(Iw, mw, cw - com)
    Ip_c = parallel_axis(Ip, mp_, cp - com)
    return m, com, Iw_c - Ip_c


# --------------------------------------------------------------------------
# geometry constants read straight off the CAD (cm, CAD frame)
# --------------------------------------------------------------------------
Y_AXIS_PLANE = -2.75     # every joint axis lies in this horizontal plane
X_HIP = {'F': 15.55, 'R': -5.05}      # pitch-axis x, front / rear
Z_ROLL = {'L': -7.40, 'R': -1.60}     # roll-axis z, left / right
THIGH_LEN = 9.50         # pitch axis -> knee axis
SHANK_LEN = 9.70         # knee axis -> foot-pad centre
FOOT_RADIUS = 1.30       # rubber pad radius  (9.70 + 1.30 = 11.00 to the ground)
LATERAL = 3.98           # roll axis -> leg sagittal plane (outboard)

BASE_ORIGIN = np.array([(X_HIP['F'] + X_HIP['R']) / 2.0,
                        Y_AXIS_PLANE,
                        (Z_ROLL['L'] + Z_ROLL['R']) / 2.0])

# The rear roll brackets were replaced by the front ones on 2026-08-23, so all
# four hips are now the same 'roll축앞다리' sub-assembly and the whole robot is
# symmetric fore-aft about x = 5.25 cm.  That moved the rear pitch axis from
# x = -3.55 to -5.05 cm, i.e. the hip spacing grew from 191 mm to 206 mm.
LEGS = {
    #        fr   lr   hip occurrence      thigh occurrence  calf occurrence   crank        rod
    'FL': ('F', 'L', 'roll축앞다리:1', '왼허벅지:1', '왼종아리발:1', '혼축링크:1', '링크:1'),
    'FR': ('F', 'R', 'roll축앞다리:2', '오른허벅지:2', '오른종아리발:2', '혼축링크:4', '링크:4'),
    'RL': ('R', 'L', 'roll축앞다리:3', '왼허벅지:2', '왼종아리발:2', '혼축링크:2', '링크:2'),
    'RR': ('R', 'R', 'roll축앞다리:4', '오른허벅지:3', '오른종아리발:3', '혼축링크:5', '링크:5'),
}

# visual mesh source document per leg part (raw STL exported in doc frame).
# Both ends now come from the same document; the per-leg occurrence transform
# in mesh_bake is what places and orients each copy.
MESH_SRC = {'F': 'hip_front', 'R': 'hip_front'}
THIGH_MESH = {'L': 'thigh_left', 'R': 'thigh_right'}
CALF_MESH = {'L': 'calf_left', 'R': 'calf_right'}

# Dynamixel horn direction vs URDF joint axis (derived from the servo
# occurrence poses: the part origin sits on the output shaft, offset toward
# the horn face).  +1 => Dynamixel CCW equals positive URDF rotation.
DXL_SIGN = {
    'FL': {'hip': +1, 'thigh': +1, 'calf': +1},
    'FR': {'hip': +1, 'thigh': -1, 'calf': -1},
    'RL': {'hip': -1, 'thigh': +1, 'calf': +1},
    'RR': {'hip': -1, 'thigh': -1, 'calf': -1},
}

# The printed thigh shell.  허벅지.ipt and 허벅지_MIR.ipt are the same solid
# (both 45.1692 cm^3) and both now carry the iProperties mass override for the
# real 3D-printed part, so this guard is a no-op against the current CAD.  It
# is kept because the override lives in the part file and is easy to lose: if
# either side ever reports the solid-ABS figure of 47.879 g again, it is pulled
# back to the real mass and its inertia scaled by the same factor (the centre
# of mass is unchanged because the geometry is identical).
THIGH_SHELL_MASS = 0.022          # kg, per side
THIGH_SHELL_FILES = ('허벅지.ipt', '허벅지_MIR.ipt')


# --------------------------------------------------------------------------
# Weighed mass
#
# The assembled robot reads 960 g on the scale while the CAD adds up to
# 912.6 g.  The missing ~47 g is the wiring harness, fasteners and adhesive
# that the model does not carry.  It is split evenly between the thighs and
# the shanks -- the servo cables run down both -- so one eighth lands on each
# of the four thigh and four calf links.
#
# Each link's inertia is scaled by the same factor as its mass, which treats
# the extra as spread through the link the way its modelled material already
# is.  Adding it as a point mass at the centroid instead would leave the
# inertia untouched and understate the swing inertia of the legs.
# --------------------------------------------------------------------------
MEASURED_TOTAL_MASS = 0.960              # kg, weighed on the assembled robot
MASS_MAKEUP_LINKS = ('thigh', 'calf')    # which links absorb the difference


# --------------------------------------------------------------------------
# Measured fore-aft weight split
#
# Standing at the 140 mm pose the feet sit directly under their own hips, so
# the support midpoint is x = 0 and the front/rear split reads the centre of
# mass directly.  Two weighings, front pair on a scale and rear pair on a block
# at the same height:
#
#     400 g / 580 g   -> front 40.8 %
#     405 g / 600 g   -> front 40.3 %
#
# so the real centre of mass is at about x = -19.5 mm, while the CAD adds up to
# -10.6 mm.  The 47 g of unmodelled wiring cannot explain it: piled at the very
# back of the body it still only moves the total by 4 mm, so the difference is
# in where the assembly puts the body's own contents.
#
# It is applied here as an explicit offset on the base link rather than by
# editing the CAD, so it stays visible and is trivially reverted.  The base
# carries 455.6 g of the 960 g total, so moving the whole robot by -8.9 mm
# means moving the base link's own centre of mass by -8.9 * 960 / 455.6.
#
# The inertia tensor is stated about the link's own centre of mass, so it is
# unchanged by relocating that point - the claim is only that the body's mass
# sits slightly further back than the CAD says, not that it is shaped
# differently.
#
# Set MEASURED_FRONT_FRACTION to None to fall back to the raw CAD figure.
# --------------------------------------------------------------------------
MEASURED_FRONT_FRACTION = 0.4055         # mean of the two weighings


# --------------------------------------------------------------------------
# Actuator: Dynamixel XL330-M288-T, from Rhoban's BAM identification
#
# https://github.com/Rhoban/bam  -- bam/params/xl330/m6.json
#
# BAM ("Better Actuator Models", ICRA 2025) fits a DC-motor + friction model to
# recorded pendulum trajectories. Six friction models m1..m6 are published.
# This package uses m6 and its jointly identified kt/R throughout. The exact
# BAM budget needs external joint torque, which Isaac Lab's actuator API does
# not expose, so XL330BamActuator implements a conservative loaded-motor
# approximation. Do not mix kt/R from one model with another model's friction
# terms: they are fitted together.
#
# The servo is voltage-controlled by its own firmware P controller:
#
#     duty = clip(error_gain * kp_firmware * (q_target - q), -1, 1)
#     tau  = kt * (duty * vin) / R  -  kt^2 * dq / R
#
# Isaac Lab's DCMotor is algebraically identical to this.  It computes
# tau = Kp*dq_err + Kd*(-dq) and clips it to tau_stall*(±1 - dq/dq_max), and
# clipping A*x to [-A, A] before subtracting B is the same as clipping A*x - B
# to [-A-B, A-B].  So the mapping below is exact, not an approximation:
#
#     stiffness        = kt * vin * error_gain * kp_firmware / R
#     damping          = kt^2 / R                       (back-EMF)
#     saturation_effort= kt * vin / R                   (stall torque)
#     velocity_limit   = vin / kt                       (no-load speed)
#     effort_limit     = kt * firmware_current_limit
#     armature         = BAM armature
#     friction         = BAM friction_base   [N*m, Isaac Sim >= 5.0]
#     viscous_friction = BAM friction_viscous
# --------------------------------------------------------------------------
# m6 adds what m1 cannot say: the loss through the gearbox grows with the
# torque passing through it.  On a 288:1 reduction that is the difference
# between a knee that lifts the body and one that does not - at the 1.75 A
# current limit m1 leaves 0.664 N*m at the joint and m6 leaves 0.422.  Measured
# on the robot, the rear knees hit the current limit and still could not stand
# up out of a crouch, which m1 says is comfortable and m6 puts on the edge.
#
# kt and R are refit per model, so they must be taken from the same file as the
# friction terms - m6's lower R is what pays for the extra loss.
BAM_XL330_M6 = {
    'kt': 0.36601349688984386,
    'R': 2.8113923539223227,
    'armature': 0.0018077432831600838,
    'q_offset': 0.0271132870444849,
    # constant part, lives on the PhysX joint
    'friction_base': 0.004771183165566,
    'friction_viscous': 0.005359668274599504,
    # load-dependent part, applied by XL330BamActuator
    'load_friction_motor': 0.2667860954283698,
    'load_friction_external': 8.515871897059342e-06,
    'friction_stribeck': 0.004676345799486616,
    'load_friction_external_stribeck': 0.08077928978935671,
    'load_friction_motor_stribeck': 1.0722918395099123e-05,
    'load_friction_external_quad': 0.004902565732332559,
    'load_friction_motor_quad': 0.009972471242139415,
    'dtheta_stribeck': 2.890372094130307,
    'alpha': 8.683259907618984,
}

# kept for reference: the Coulomb-only fit this package used before
BAM_XL330_M1 = {
    'kt': 0.3866957639281311,          # N*m/A, at the output shaft
    'R': 4.017129222290597,            # Ohm
    'armature': 0.0018141672784458866,  # kg*m^2, reflected to the joint
    'friction_base': 0.01283272036582759,     # N*m, Coulomb
    'friction_viscous': 0.003661672282824312,  # N*m*s/rad
    'q_offset': 0.030871000250528358,
}

# duty cycle produced per (firmware kp * radian of error).
# = (encoder counts per rev / 2pi) / (kp divisor * PWM limit), from BAM's
# XL330Actuator: 4096/(2*pi) / (256 * 885)
XL330_ERROR_GAIN = (4096.0 / (2.0 * np.pi)) / (256.0 * 885.0)
XL330_CURRENT_LIMIT = 1.75         # A, XL330 firmware current limit (Rhoban Microban constants.py)

SUPPLY_VOLTAGE = 7.4               # V, 2S LiPo wired straight to the servos
FIRMWARE_KP = 200                  # XL330 Position P Gain register
# Measured on the robot, closed loop, standing and then walking:
#   kp 400  a 7.5 Hz limit cycle in all three gyro axes - 99 % of the yaw
#           rate power in one band - and 90 degrees of yaw drift in 6 s.
#           1431 mA of it was the servos fighting each other.
#   kp 125  no oscillation, because the servos stopped following: 18 deg
#           of mean tracking error, 47 deg at worst, and the whole robot
#           frozen at the gyro noise floor. Quiet, and not obeying.
#   kp 200  a real gait - 8.5 deg of joint motion, 8.1 deg mean tracking
#           error, 1.1 deg of yaw drift, and 7 % in the 7.5 Hz band.
#           Three consecutive 10 s runs at 0.5 m/s, none of them fell.
# Rhoban run their own RL policy on the same servo at 125 (Rhoban Microban
# constants.py, KP_RL), but they are balancing a biped on one foot at a
# time; a quadruped keeps four feet down and can afford the stiffness.
# DAMPING_SCALE stays where it is: damping is kt^2/R, which does not
# depend on kp, so halving the stiffness raises the damping ratio by
# sqrt(2) on its own - the direction the measurements already show
# (zeta 0.37 at kp 400 against 0.50 at kp 125).
# An earlier static test picked 600: holding a fixed target, 400 let the knees
# sag about 9 degrees under load and stalled them on a lift, while 600 held the
# 170 mm pose to within 3 degrees at under 50 mA per joint.
#
# A closed-loop policy changes that measurement's meaning. It rewrites every
# target at 50 Hz, so steady sag is something it corrects rather than something
# it suffers, and on the robot it held 170 mm for thirty seconds at gains as
# low as 100. What 600 buys instead is a resonance: a swept-sine on the
# standing robot gives a gain of 1.50 at 1.5 Hz at kp=600 against 1.23 at
# kp=400, so the higher gain amplifies exactly the band the shimmer lives in.
# 400 is the compromise - enough bandwidth that commands are actually executed
# (gain 1.11 at 1 Hz, against 0.52 at kp=125, where the servo simply ignores
# the policy) without the peak.
#
# The stall-on-a-lift finding still stands, and still applies to standing up
# from folded, which is a much larger load than standing still.

# Measured damping correction.
#
# The same swept sine, run on the robot and then identically in simulation:
#
#             hardware            simulation
#   kp 400    fn 1.20  zeta 0.37  fn 1.85  zeta 0.92
#   kp 600    fn 1.40  zeta 0.34  fn 1.90  zeta 0.52
#
# The simulated robot is better damped than the real one at both gains, and the
# gap is what the standing policy's 4 Hz shimmer comes out of: it was trained
# against a machine that settles and deployed onto one that rings.
#
# The cause is almost certainly not the motor. `damping` here is the back-EMF
# term kt^2/R, which the real motor has too. What the real robot has *extra* is
# compliance the URDF does not model - printed brackets, bearing play, the
# pushrod - which adds an underdamped mode behind every joint. Isaac Lab has no
# convenient series spring, so the effect is absorbed into the joint damping
# instead. That makes this an empirical fit, not a physical measurement, which
# is why it is a named scale factor sitting next to the physics rather than an
# edit to the formula.
#
# zeta scales with damping at fixed stiffness, so matching 0.92 -> 0.37 is a
# factor of 0.402. Set to 1.0 to get the physical back-EMF value back.
DAMPING_SCALE = 0.402


def actuator_block():
    b = BAM_XL330_M6
    kt, R, vin = b['kt'], b['R'], SUPPLY_VOLTAGE
    stall = kt * vin / R
    motor_limit = min(kt * XL330_CURRENT_LIMIT, stall)
    # Mirror XL330BamActuator's conservative loaded, zero-speed approximation.
    provisional = motor_limit * (1.0 - b['load_friction_motor'])
    stribeck_loss = (
        b['friction_stribeck']
        + b['load_friction_external_stribeck'] * provisional
        + b['load_friction_external_quad'] * provisional * provisional
    )
    net_effort_at_current_limit = max(
        0.0, provisional - stribeck_loss - b['friction_base']
    )
    return {
        'model': 'Dynamixel XL330-M288-T',
        'source': "Rhoban BAM, bam/params/xl330/m6.json (load-dependent friction)",
        # --- raw identified parameters, do not edit
        'bam_model': 'm6',
        'kt': kt,
        'R': R,
        'error_gain': XL330_ERROR_GAIN,
        'friction_base': b['friction_base'],
        'friction_viscous': b['friction_viscous'],
        # --- your hardware choices
        'supply_voltage': vin,
        'firmware_kp': FIRMWARE_KP,
        'firmware_current_limit': XL330_CURRENT_LIMIT,
        # --- derived, fed straight into Isaac Lab's DCMotorCfg
        'stiffness': kt * vin * XL330_ERROR_GAIN * FIRMWARE_KP / R,
        'damping': kt * kt / R * DAMPING_SCALE,
        'damping_backemf': kt * kt / R,
        'damping_scale': DAMPING_SCALE,
        'saturation_effort': stall,
        'effort_limit': motor_limit,
        'velocity_limit': vin / kt,
        'armature': b['armature'],
        'friction': b['friction_base'],
        'dynamic_friction': b['friction_base'],
        'viscous_friction': b['friction_viscous'],
        # --- load-dependent terms, consumed by XL330BamActuator
        'load_friction_motor': b['load_friction_motor'],
        'friction_stribeck': b['friction_stribeck'],
        'load_friction_external_stribeck': b['load_friction_external_stribeck'],
        'load_friction_external_quad': b['load_friction_external_quad'],
        'dtheta_stribeck': b['dtheta_stribeck'],
        'alpha': b['alpha'],
        'net_effort_at_current_limit': float(net_effort_at_current_limit),
        # --- reference points
        'datasheet_stall_torque_5v': 0.52,
        'datasheet_no_load_speed_5v': 8.48,
        'note': 'the gearbox eats load_friction_motor (27%) of whatever the motor '
                'produces, so the torque that reaches the joint at the current limit is '
                'net_effort_at_current_limit, not effort_limit. '
                'stiffness, stall torque, and no-load speed scale with supply_voltage; '
                'the current-limited effort does not. stiffness also scales with firmware_kp. '
                'Rhoban Microban uses kp=125 for RL walking '
                'on a biped; this quadruped carries static load on all four legs, where '
                'kp=125 would let the knees sag ~36 deg. Hardware load sweeps first '
                'selected 600; firmware_kp is now 200, which is what the '
                'robot runs and what the exported hardware map carries.',
    }


def link_origin_cad(leg):
    """Frame origins of the four links of one leg, in CAD cm."""
    fr, lr = LEGS[leg][0], LEGS[leg][1]
    out = -1.0 if lr == 'L' else +1.0          # CAD +Z is the robot's right
    z_leg = Z_ROLL[lr] + out * LATERAL
    hip = np.array([X_HIP[fr], Y_AXIS_PLANE, Z_ROLL[lr]])
    thigh = np.array([X_HIP[fr], Y_AXIS_PLANE, z_leg])
    calf = np.array([X_HIP[fr] - THIGH_LEN, Y_AXIS_PLANE, z_leg])
    foot = np.array([X_HIP[fr] - THIGH_LEN, Y_AXIS_PLANE - SHANK_LEN, z_leg])
    return {'hip': hip, 'thigh': thigh, 'calf': calf, 'foot': foot}


def to_urdf_vec(v_cad):
    return M @ np.asarray(v_cad, dtype=float) * CM


def inertial_block(m, com_cad, I_cad, origin_cad):
    """URDF <inertial> for a body whose merged properties are given in CAD."""
    com_link = M @ (com_cad - origin_cad) * CM
    I = (M @ I_cad @ M.T) * INERTIA
    return {
        'mass': float(m),
        'com': [float(x) for x in com_link],
        'inertia': {
            'ixx': float(I[0, 0]), 'iyy': float(I[1, 1]), 'izz': float(I[2, 2]),
            'ixy': float(I[0, 1]), 'ixz': float(I[0, 2]), 'iyz': float(I[1, 2]),
        },
    }


def box_from_bbox(lo_cad, hi_cad, origin_cad):
    lo = M @ (lo_cad - origin_cad) * CM
    hi = M @ (hi_cad - origin_cad) * CM
    lo, hi = np.minimum(lo, hi), np.maximum(lo, hi)
    return {'size': [float(x) for x in (hi - lo)],
            'origin': [float(x) for x in (lo + hi) / 2.0]}
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

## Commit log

2026-09-24 Micro Dog: open hardware release
    Micro Dog quadruped design: URDF, visual meshes, STEP, flattened USD,
    parameters, Autodesk Inventor source, regeneration tools and
    documentation. The BOM will follow in a later update.
    Hardware and docs: CC BY-NC-SA 4.0. tools/: GPL-3.0-or-later.
    [BMS.ipt, XL,XC-330.ipt, XL,XC-330_MIR.ipt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]
2026-09-24 Add the walking policy (gamepad button A) and its deployment contract
    policy/micro_dog_walk.pt is the RSL-RL checkpoint deployed on the robot's
    button A; its actor matches the deployed export exactly. The JSON gives
    the 45-D observation, action formula, joint order and hardware settings.
2026-09-24 Docs: materials per creator's notes (TPU-95A feet, aluminium knee links)
2026-09-24 Docs: frame is PLA; note that CAD masses assume ABS density
2026-09-24 Docs: all printed parts are PLA
2026-09-24 Review fixes: Korean README materials/licence, policy torque limit note
